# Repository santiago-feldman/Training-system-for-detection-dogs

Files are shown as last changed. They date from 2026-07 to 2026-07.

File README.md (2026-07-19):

# Training-system-for-detection-dogs
Electronic engineering final project (electronic equipment design) | ITBA

### Group members:

- Feldman, Santiago
- Greco, Trinidad Eugenia
- Rodriguez, Juan Martín
- Singermann, Nicolás Pablo

### Faculty staff:

- Carrillo del Pino, Manuel Esteban
- Gasparini, Ignacio
- Orchessi, Walter Hugo
- Regazzoni, Pablo

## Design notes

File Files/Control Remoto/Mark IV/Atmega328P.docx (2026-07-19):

Conexiones básicas para el Atmega 328P (DIP)

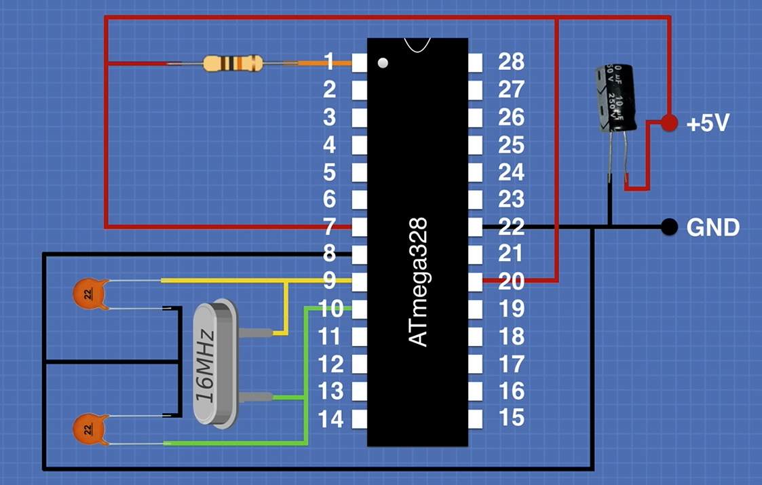
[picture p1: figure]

R de 10k, multicapas de 22pF, y electrolítico de 10 micros (opcional)

- Notar que este conexionado no contempla el regulador de 5v, asume que le llega la tensión ya regulada.
- Tampoco tiene un botón de Reset

Como es de encapsulado DIP, se puede cargar el código de 2 formas distintas:

- Simplemente colocarlo en la placa del arduino uno y cargar el programa
- Teniendo el micro en la proto, usar Tx, Rx y Reset del arduino uno para cargar el programa

En caso de ser SMD, se puede usar un adaptador FTDI (Básicamente son USB to Serial Converters)

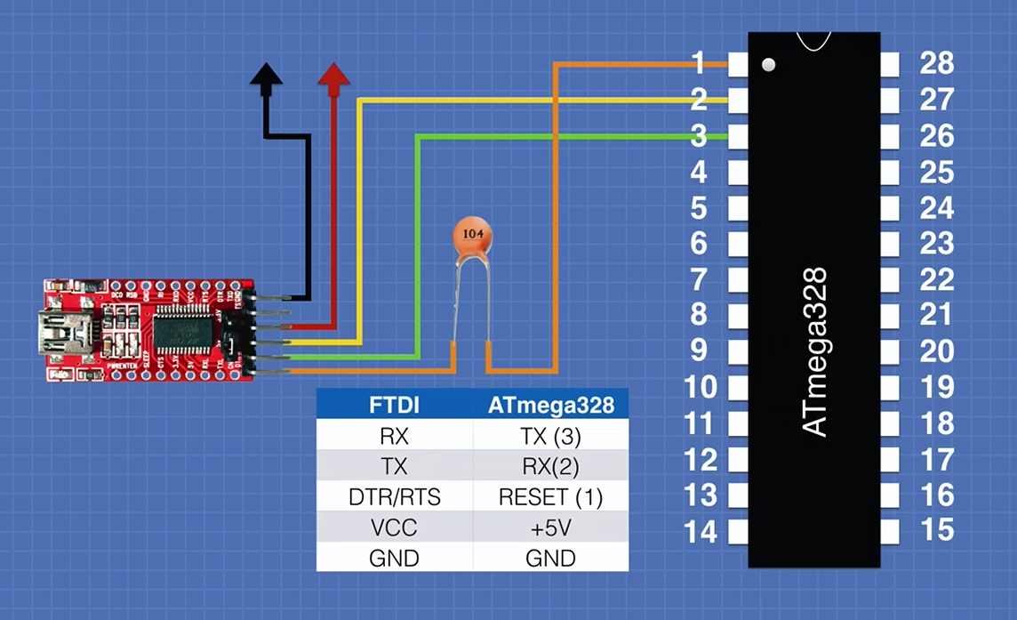
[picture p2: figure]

Multicapa de 100n. Fuente: https://www.youtube.com/watch?v=Sww1mek5rHU&t=915s

(https://www.youtube.com/watch?v=Sww1mek5rHU&t=915s)

Importante al hacer PCB con el 328P SMD:

- Colocar un botón de RST en el PCB
- Dejar salida de 2 pines, conectados a Tx y Rx, para poder cargar programa al micro en caso de ser necesario (asegurarse que antes de desoldarlo tenga cargado el programa indicado y que esté funcionando)
- 2 entradas para la alimentación de la pila, idealmente un molex o soldar directo
- 2 salidas para el pulsador del control

Video Clave para cargarle un programa al 328P

- https://www.youtube.com/watch?v=jy-UyMF7zr8

En resumen, se usa otro arduino (use el Nano) para cargarle un programa a otro micro (328P) vía SPI. Para esto primero se le carga un programa de ejemplo al Nano llamado ArduinoISP. Seleccionando en Herramientas → Programador → Arduino as ISP, le cargué el bootloader al 328P, y luego el Sketch → Cargar usando programador, va a subir el programa que se tenga abierto al 328P!!

En el PCB esto va a tener leves cambios, no voy a usar el adaptador FTDI, por lo que necesita 4 pines que salgan hacia afuera para poder programarlo (MISO, MOSI, SCK, SS). Y no olvidarse que el NRF24l01 usa SPI también

Próximos pasos (cada paso asume que el anterior fue exitoso)

1. Probar en Proto alimentando al 328P con el regulador de 3.3V (En teoría se puede alimentar al micro con 3.3V)
2. Probar el control remoto con el 328P como control, y el arduino Nano como el lanzador. Acá estar atento a si el regulador suministra la suficiente corriente para el 328P + NRF24l01
3. Ya se está listo para diseñar el PCB, desoldar el 328P SMD del Nano, para ver su encapsulado
4. Diseñar PCB con las consideraciones debidas (atento al encapsulado del 328P SMD). Que el PCB tenga botón de reset (puede ser SMD) y un LED (también SMD) simplemente para tener la posibilidad de debugeo
5. Hacer PCB
6. Testear control remoto
7. Diseñar carcaza para el control remoto

Imágenes útiles

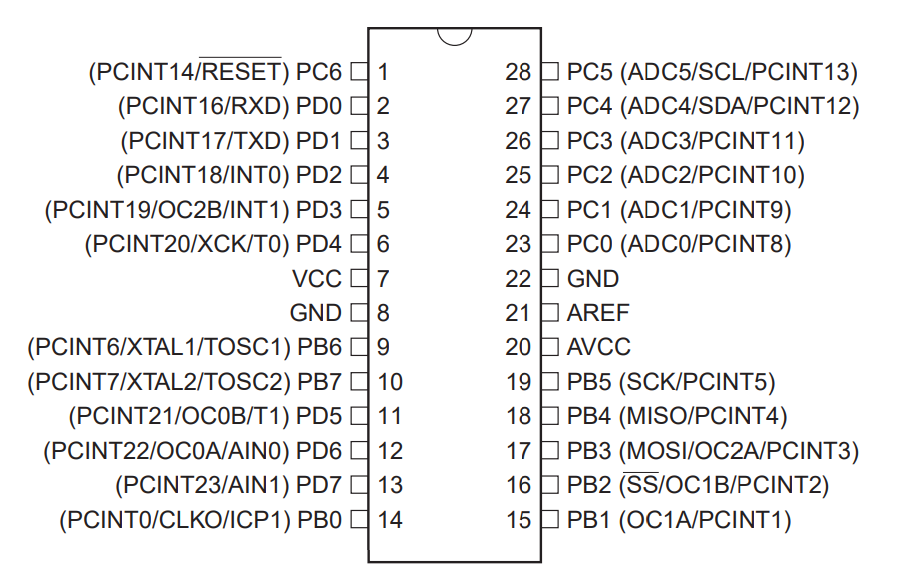
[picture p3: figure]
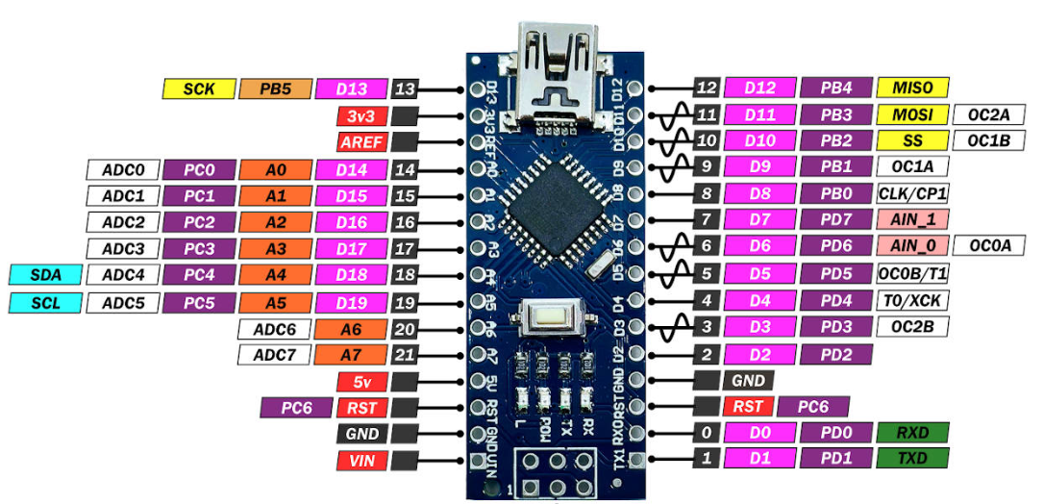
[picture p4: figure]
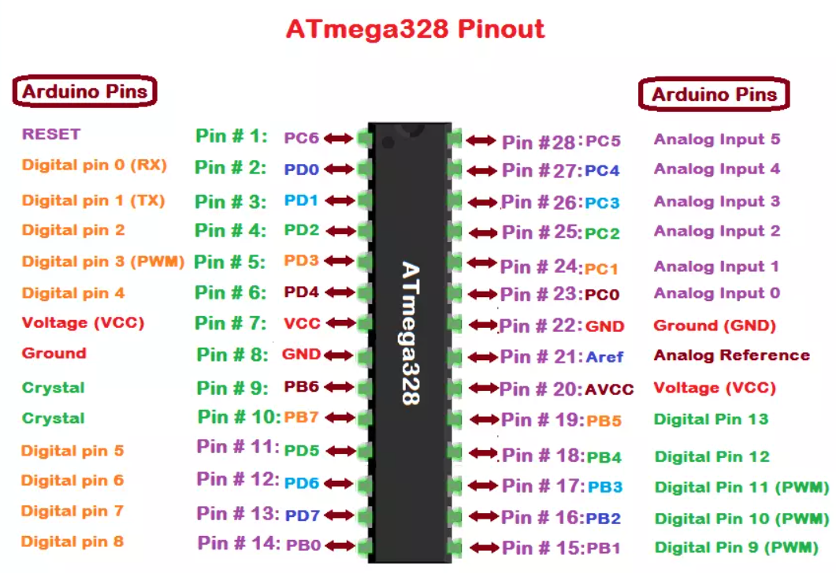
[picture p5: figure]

- Comenzando con el PCB

El arduino nano tiene un ATMEGA328P SMD de 32 pines, bastante seguro que es el encapsulado MLF, el cual tiene un pad en la cara inferior, que debe ser soldado a GND.

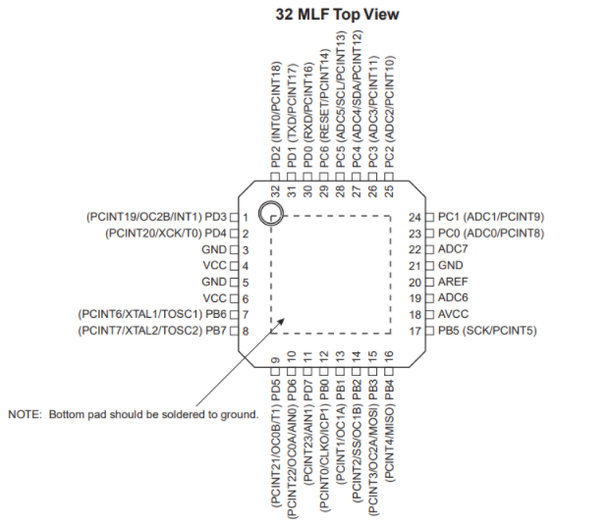
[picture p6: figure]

Me parece una buena idea poner un LED SMD para posible debugeo → SMD 1206

No olvidarse de colocar 2 entradas para la alimentación con la pila (pueden ser 2 pads), y 2 salidas para el pulsador

Tambien se puede agregar un SW SMD para el reset

Para el regulador SMD → SOT-223, y la tab es Vout

Atento a los footprints antes de planchar → Especialmente al SW del Reset, al LED, al Electrolítico SMD, y al micro

Hay que cambiar el código! Conecte el Led de Debug a PD2!

Y se conecto el 2do botón!

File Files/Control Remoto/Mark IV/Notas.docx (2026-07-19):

Cosas a mejorar frente al Mark III

PCB

- Que el PCB tenga agujeros para sujeción a la carcasa (Pueden ser 2/3/4)
- Chequear la orientación del NRF24
- Ambos botones conectados a pines con IRQ
- Tener pin de salida al RST del micro para poder cargar programa más fácilmente
- Necesito preset para ajustar las resistencias para la boost
- Las salidas a los pulsadores y a la alimentación con molex, no soldado a la placa
- Que el cristal sea SMD (Usar el que ya se tiene del Nano)

Carcasa

- Considerar en la carcasa que adentro va el portapila AAA
- Ver de usar botones más pequeños
- Que la carcasa tenga el logo

Cambios en el código

- Los pulsadores ahora están en PD2 y PD3 que tienen IRQ externas
- El LED para debugeo ahora está en PD4

Testeos antes de hacer la placa

- Chequear todos los footprints antes de planchar, especialmente el del cristal SMD

Testeos después de hacer la placa

- Probar tensión de salida de la boost previo a conectar el NRF24
- Sacar buenas fotos a la placa antes de hacer nada

Lista para comprar componentes

- MCP1640 (SOT-23) x1 (https://www.elemon.com.ar/products/detail/code/CI2707272)
- C 4.7uF multicapa SMD (0805) x1
- C 4.7uF multicapa SMD (1206) x1
- C 10uF multicapa SMD (0805) x1
- C 10uF multicapa SMD (1206) x1
- L 4.7uH SMD (1007) x1 (https://www.elemon.com.ar/products/detail/code/FI1512580)
- R 750K SMD (0805) x1
- R 220K SMD (0805) x1
- R 560K SMD (0805) x1
- R 2K SMD (0805) x1
- Preset 10k

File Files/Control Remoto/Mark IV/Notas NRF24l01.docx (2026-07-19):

- NRF24l01

Es un transceptor (Emisor y Receptor) de radiofrecuencia a 2.4GHz que usa modulación FSK, logrando alta inmunidad al ruido.

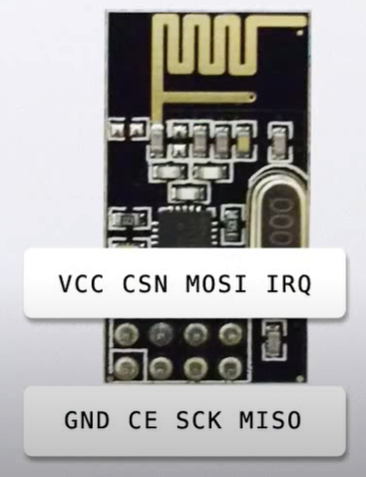
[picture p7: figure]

Pinout NRF24l01

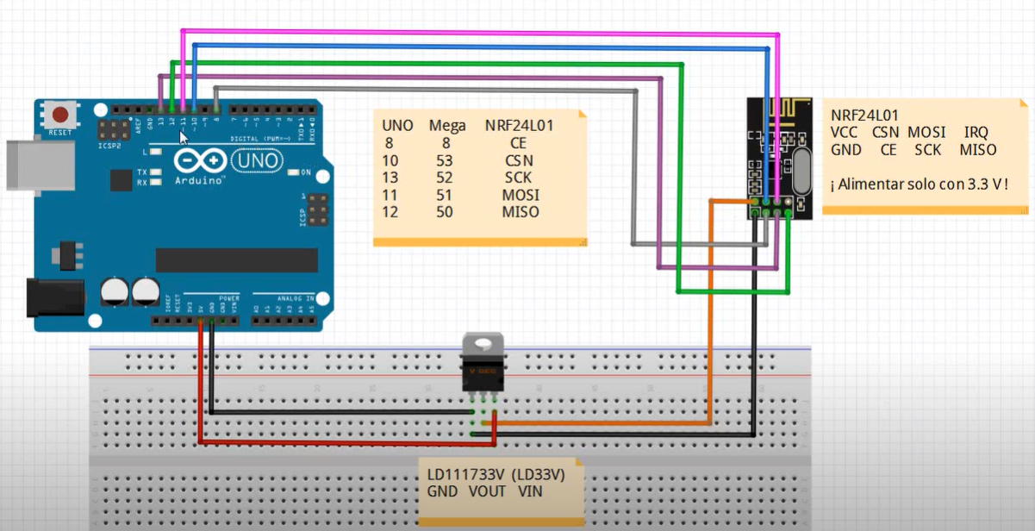
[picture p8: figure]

Dispositivo Base

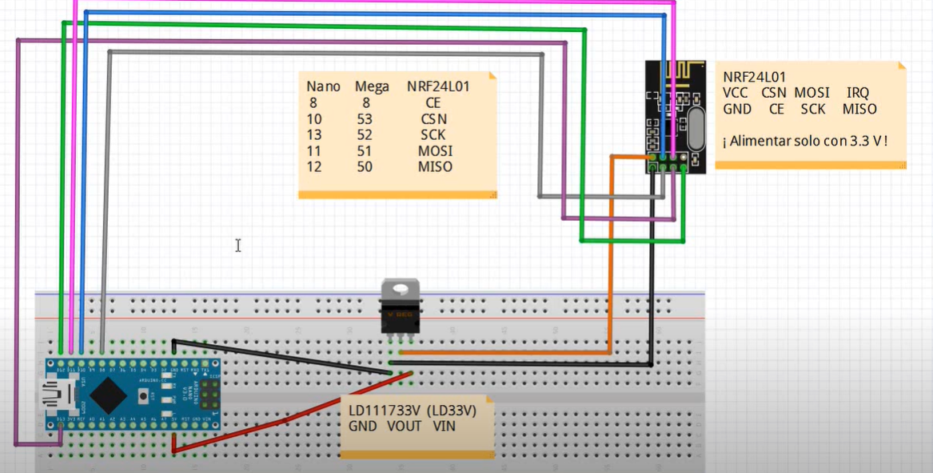
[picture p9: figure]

Dispositivo Remoto

Se verifica la integridad de los datos recibidos (con un CRC)

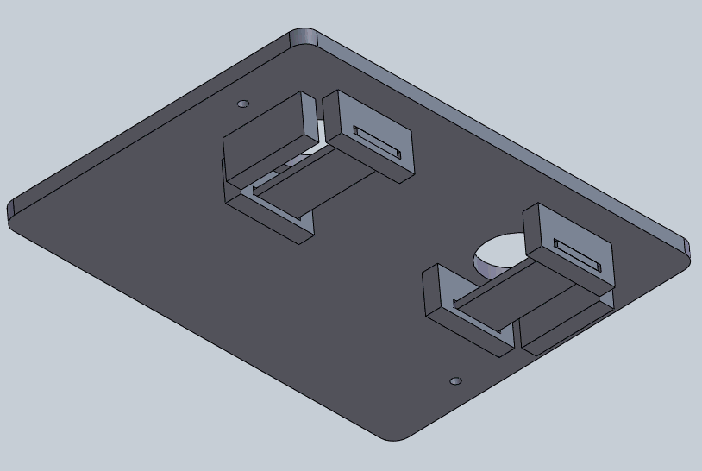
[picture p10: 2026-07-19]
Files/Control Remoto/Sujecion_RC.png

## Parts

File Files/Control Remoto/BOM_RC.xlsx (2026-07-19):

Designator | Descripción | Quantity
C1, C2 | 22pF | 2
C3 | 4.7uF | 1
C4 | 10uF | 1
D1 | AP1608SGC (Red Led) | 1 | Red LED SMD
J1, J2, J3 | MOLEX2 | 3
J4 | JUMPER | 1
L1 | CB2518T4R7MR (4.7uH) | 1 | 4.7uH SMD
P1 | NRF24 | 1
R1, R2 | 10k | 2
R3, R4 | 1k | 2
R5 | 560k | 1
R6 | 2k | 1
R8 | 750k | 1
R9 | 220k | 1
R10 | 10k | 1
S1 | SW | 1
SUJECION 1, SUJECION 2 | SUJECION | 2
U1 | ATMEGA328PB-ANR | 1
U2 | MCP1640CT-I/CHY | 1
Y1 | CSTNE16M0V530000R0 (Cristal 16MHz) | 1 | Cristal 16MHz SMD

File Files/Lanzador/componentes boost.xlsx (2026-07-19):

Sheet: Hoja1
2° Etapa | UC3843 | Comentario |  | 1° Etapa | MT3608 | Comentario
I_sense | 0.5 | Configurada |  | Io_max | 0.25
Vin | 12 | Salida de la primer etapa |  | Vin | 3.7
Vo_max | 90 |  |  | Vo | 12
Vo_min | 40 |  |  | I_in_media | 0.811 | Suponiendo CCM y eficiencia 100%
fs | 100000 | hasta 500kHz |  | I_in_potencia | 0.9538950715 | Por balance de Potencias y eficiencia n
L_boundary | 0.000208 | Buscamos menor para DCM |  | n | 0.85 | Eficiencia del módulo
Componentes | Valor | Comentario | Modelo | link
L | 0.0001 | I_max = 0.5A según I_sense
C_t | 2.2e-09 | Según grafica datasheet, ceramico preciso |  |  |  | MOSFET | IRF630 | Vds>200V, I_ds>1A, P
R_t | 7818.181818 | R_t para 100kHz |  |  |  | Diodo Ultra Rápido | UF4005 | through hole
R_t_real | 8200 |  |  |  |  | Diodo Ultra Rápido | ES1J | SMD
fs | 95343.68 | fs para Rt real
L_boundary_real | 0.0002181581395 | L boundary para fs real
t_dead | 3e-07 | según grafica Ct=1nF->t_dead= 300ns
D_max | 0.97 | Duty máximo según Ct, mínimo 0.87
R_sense | 2 | Vth = 1V, define maxima corriente en L.
R_lp | 1000 | RC para señal de sense
C_lp | 4.7e-10 | RC para señal de sense
Rf_top_max | 50000 | i_bias=2uA, DeltaVo_max=100mV
DeltaVo | 0.44 | Consecuencia de i_bias=2uA
Rf_top | 220000
Rf_bottom | 82000.00
Vo | 9.21 | Vo según Rtop y Rbott
Rf_bottom_min | 6285.71 | Vo_max
Rf_bottom_max | 14666.67 | Vo_min
Rf_bott_1 | 6200
Rf_bott_2_1 | 50000 | preset
Rf_bott_2_2 | 10000
Rf_bott_real | 14533.33
i_f | 0.000298013245 | Corriente de perdida en feedback
Rcomp | 100000 | Mínimo por OpAmp interno, Rcomp>7k
Ccomp | 1e-08
f_polo | 159.15
G_dc | 1.67
diodo_pwm | SS14 | Shottky, Vf<0.3V a 200mA
Rgate | 22 | Limita la corriente de gate
Igate_max | 0.545
C_vcc | 1e-07 | Ceramico multicapa
C_vref | 1e-06 | Ceramico multicapa

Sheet: Hoja2
0.002
0.5ms | 1ms | 1000
 |  | 2000

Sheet: Comp
2° Etapa | UC3843 | Comentario |  | 1° Etapa | MT3608 | Comentario
I_sense | 0.5 | Configurada |  | Io_max | 0.25 |  |  | Eo | 13.536 |  | Epump | 0.000846
Vin | 12 | Salida de la primer etapa |  | Vin | 3.7 |  |  | Co | 0.00188 |  | Cpump | 4.7e-07
Vo_max | 90 |  |  | Vo | 12 |  |  | Vo | 120 |  | Vpump | 60
Vo_min | 40 |  |  | I_in_media | 0.811 | Suponiendo CCM y eficiencia 100% |  |  |  |  | Npump | 16000
fs | 100000 | hasta 500kHz |  | I_in_potencia | 0.9538950715 | Por balance de Potencias y eficiencia n |  |  |  |  | Ts | 1e-05
L_boundary | 0.000208 | Buscamos menor para DCM |  | n | 0.85 | Eficiencia del módulo |  |  |  |  | T_total | 0.16
Componentes | Valor | Comentario | Modelo | link
L | 0.0001 | I_max = 0.5A según I_sense
C_t | 2.2e-09 | Según grafica datasheet, ceramico preciso |  |  |  |  |  | Vds>200V, I_ds>1A, P
R_t | 7818.181818 | R_t para 100kHz
R_t_real | 8200
fs | 95343.68 | fs para Rt real |  |  |  | Diodo Ultra Rápido | UF4005 | through hole
L_boundary_real | 0.0002181581395 | L boundary para fs real
t_dead | 3e-07 | según grafica Ct=1nF->t_dead= 300ns
D_max | 0.97 | Duty máximo según Ct, mínimo 0.87
R_sense | 2 | Vth = 1V, define maxima corriente en L. 1/4W |  |  |  |  |  |  | Cantidad |  | Componente | Modelo | Tipo | Cantidad
R_lp | 1000 | RC para señal de sense |  |  | x | L | 100uH, 1A | SMD | 2 | elemon | Diodo Ultra Rápido | ES1J | SMD | 2
C_lp | 4.7e-10 | RC para señal de sense |  |  | x | C_t | 2.2nF,16V,NP0 | 1206 | 5 | elemon | MOSFET | IRF630 | THT | 2
Rf_top_max | 50000 | i_bias=2uA, DeltaVo_max=100mV |  |  |  | R_t | 8.2k | 1206 | 5 |  | diodo Schottky | SS14 | SMD | 2
DeltaVo | 0.44 | Consecuencia de i_bias=2uA |  |  | x | R_sense | 2 ,1/4W o mas | 1206 | 5 | elemon | Driver PWM | UC3843D8 | SMD | 2
Rf_top | 220000 |  |  |  |  | R_lp | 1k | 1206 | 5 |  | Regulador 5V | UA78M05 | SMD | 2
Rf_bottom | 6800.00 |  |  |  |  | C_lp | 470p,16V,NP0 | 0805 | 5 | elemon | Oscilador | NE555DR | SMD | 2
Vo | 83.38 | Vo según Rtop y Rbott |  |  |  | Rf_top | 220k | 1206 | 5 |  | MOSFET | IRF640S | SMD | 2
Rf_bottom_min | 6285.71 | Vo_max |  |  |  | Rf_bott_1 | 6.2k | 1206 | 5
Rf_bottom_max | 14666.67 | Vo_min |  |  |  | Rf_bott_2 | 10k | 1206 | 5
Rf_bott_1 | 6800 |  |  |  |  | Rf_preset | 50k | 1206 | 5 | elemon
Rf_bott_2_1 | 0 | preset |  |  |  | R_comp | 100k | 0805 | 5
Rf_bott_2_2 | 10000 |  |  |  | x | C_comp | 10n,16V,NP0 | 0805 | 5 | elemon
Rf_bott_real | 6800.00 |  |  |  | x | R_g | 22, 1/4W | 1210 | 5 | elemon
i_f | 0.0003968253968 | Corriente de perdida en feedback |  |  |  | C_vcc | 100n,16V | 1206 | 5
Rcomp | 100000 | Mínimo por OpAmp interno, Rcomp>7k |  |  |  | C_vref | 1u,16V | 1206 | 5
Ccomp | 1e-08 |  |  |  |  | C_vin_1 | 100n,16V | 1206 | 2
f_polo | 159.15 |  |  |  | x | C_vin_2 | 470u,25V | THT/SMD | 2 | elemon | CA3629295
G_dc | 15.16 |  |  |  |  | Co_1 | 100n, 150/200V | THT/SMD | 2
diodo_pwm | SS14 | Shottky, Vf<0.3V a 200mA |  |  |  | Co_2 | 100u, 150/200V | THT/SMD | 2
Rgate | 22 | Limita la corriente de gate |  |  | x | Diodo Ultra Rápido | ES1J | SMD | 2 | elemon
Igate_max | 0.545 |  |  |  | x | MOSFET | IRF630 | THT | 2 | elemon
C_vcc | 1e-07 | Ceramico multicapa |  |  | x | diodo Schottky | SS14 | SMD | 2 | elemon
C_vref | 1e-06 | Ceramico multicapa |  |  | x | Driver PWM | UC3843D8 | SMD | 2 | gm elect
 |  |  |  |  |  | Regulador 5V | UA78M05 | SMD | 2 | elemon
 |  |  |  |  |  | Oscilador | NE555DR | SMD | 2 | elemon
f_lp | 338799.2953
f_lp_2
clp2 | 1e-09
rlp2 | 470

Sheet: Transistores Rdson
Item | Modelo | Cantidad
1 | AO3401 | 5
2 | AO3400 | 5 | 0.0175
3 | AO4423 | 6
4 | AO4407 | 4
5 |  | 3

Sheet: SoftStartSW
SW1 |  |  |  |  | SW2
Calculos |  |  | Componentes |  | Calculos |  |  | Componentes
I_inrush | 1.00 |  | I_inrush | 1.055916893 | I_inrush | 0.25 |  | I_inrush | 0.09488518519 | 0.09488518519
R1 | 100000 | R pull up | R1 | 100000 | R1 | 100000 | R pull up | R1 | 100000
R2 | 2777.78 | R g | R2 | 2700 | R2 | 4347.83 | R g | R2 | 2700
C1 | 8.586666667e-09 |  | C1 | 8.2e-09 | C1 | 2.51447619e-08 |  | C1 | 1e-07
i_g_r1 | 1.352380952e-05 |  | i_g_r1 | 1.4e-05 | i_g_r1 | 9.688095238e-05 |  | i_g_r1 | 9.7e-05
i_g_r2 | 0.0008451428571 |  | i_g_r2 | 0.0008518518519 | i_g_r2 | 0.0005317380952 |  | i_g_r2 | 0.0008518518519
i_g | 0.0008586666667 |  | i_g | 0.0008658518519 | i_g | 0.0006286190476 |  | i_g | 0.0009488518519
gfm | 21 |  |  |  | gfm | 21
VDD | 3.7 |  | VDD | 3.7 | VDD | 12 |  | VDD | 12
Vth | 2.3 |  |  |  | Vth | 2.3
Vpl | 2.348 |  | Vpl | 2.300 | Vpl | 2.312 |  | Vpl | 2.300
Vsg | 3.6 |  | Vg | 0.09727361246 | Vsg | 11.5 |  | Vg | 0.3154819864
Vsg_max | 25 |  | Vsg | 3.602726388 | Vsg_max | 25 |  | Vsg | 11.68451801
Ciss | 2.6e-09 |  |  |  | Ciss | 2.6e-09
Coss | 3.7e-10 |  |  |  | Coss | 3.7e-10
Cload | 1e-05 |  | Cload | 1e-05 | Cload | 1e-05 |  | Cload | 1e-05
 |  |  | dt | 3.50406365e-05 |  |  |  | dt | 0.001264686366
 |  |  | V12 | 10
 |  |  | Rtop | 100000
 |  |  | Rbott | 82000
 |  |  |  | 4.505494505

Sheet: Componentes DriverLanzador
Switch Load |  |  |  | Disparo Rele |  |  |  | Bleeding |  |  |  | PlacaESP
Componente | Modelo | Cantidad | Proveedor | Componente | Modelo | Cantidad | Proveedor | Componente | Modelo | Cantidad | Proveedor | Componente | Modelo | Cantidad | Proveedor
MOSFET-P | IRF7425PBF | 2 | Elemon | optocoplador | LTV817S | 1 | Elemon | zener 8.2V | BZV55C8V2 | 1 | SDV | Sensor | BME280 | 1 | Elemon
MOSFET-N | 2N7002 | 2 | SDV | diodo rele | 1n4148W | 1 | SDV | zener 12V | BZV55C12 | 1 | SDV | Regulador LDO | MCP1826S | 2 | Elemon
Cap_GD | 10n | 2 | SDV | diodo solenoide | ES1J | 1 | Elemon | MOSFET-N | IRFL110 | 1 | Elemon | Pila | P18650C | 1 | SDV
 |  |  |  | Rele | HJQ-13F-2ZP | 1 | SDV | MOSFET-N | 2N7002 | 1 | SDV
 |  |  |  | Rdiodo | 190 |  |  | Res | 2.7k 3W | 4 | SDV
Boost 80V
Componente | Modelo | Cantidad | Proveedor
Co | 47uF 160V | 1 | SDV

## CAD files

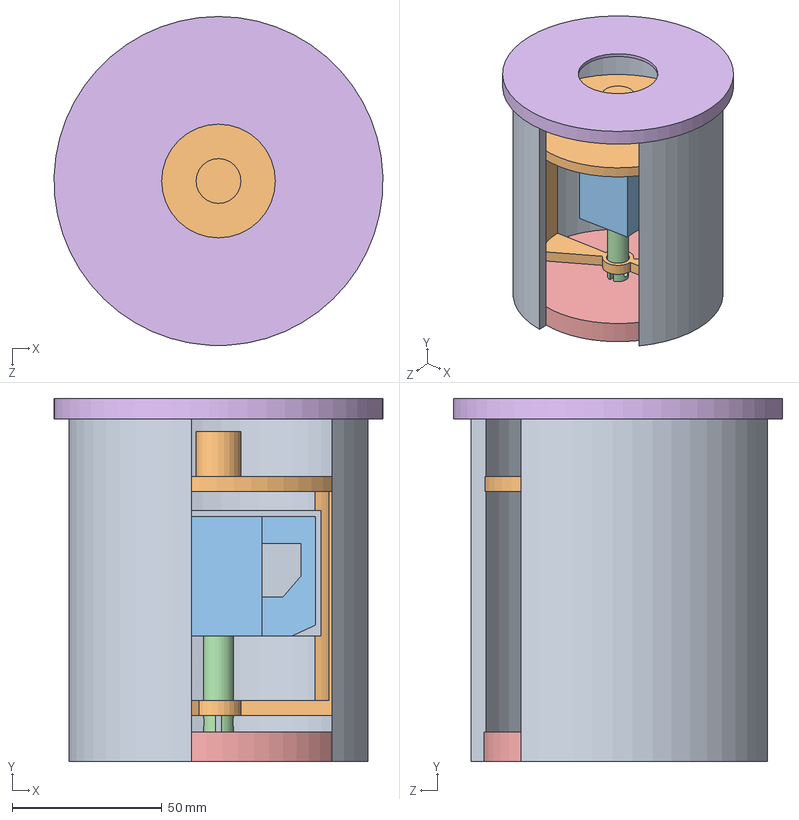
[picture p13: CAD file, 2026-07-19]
Files/SolidWorks/Lanzador/Ensamblaje lanzador.SLDASM
110.0 x 121.5 x 110.0 mm
Lanzador cilindrico
Lanzador cilindrico p2
modelo solenoide
palito
tapa lanzador
tapa pelota

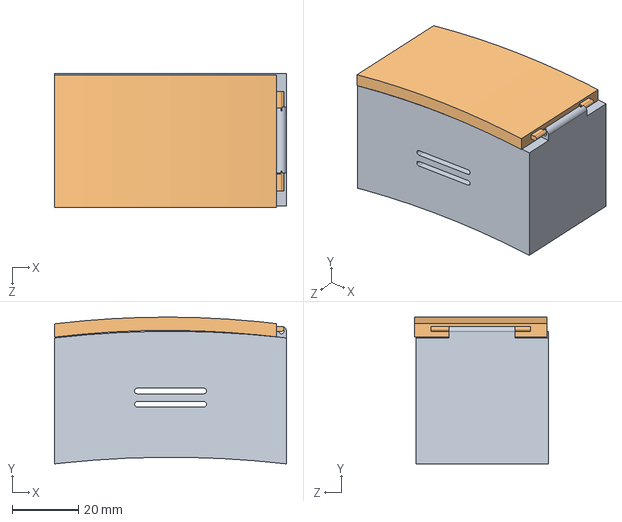
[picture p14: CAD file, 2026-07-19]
Files/SolidWorks/Lanzador/Ensamblaje1.SLDASM
70.0 x 44.3 x 40.3 mm
TAG_p1
Tapa_p1

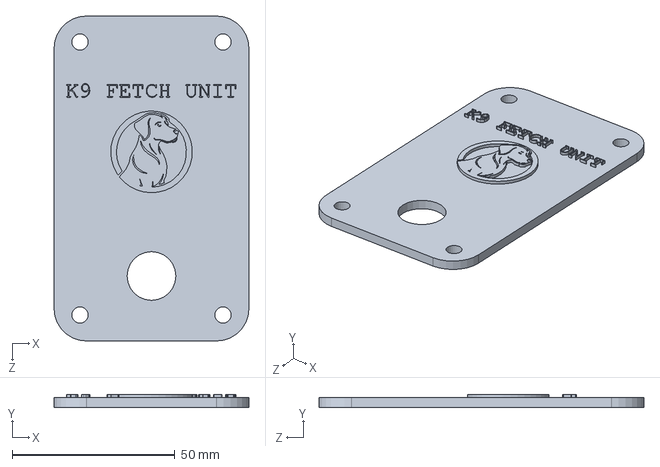
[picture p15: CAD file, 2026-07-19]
Files/Control Remoto/Mark IV/Solid/Tapa_RC.SLDPRT
60.0 x 4.00 x 100.0 mm

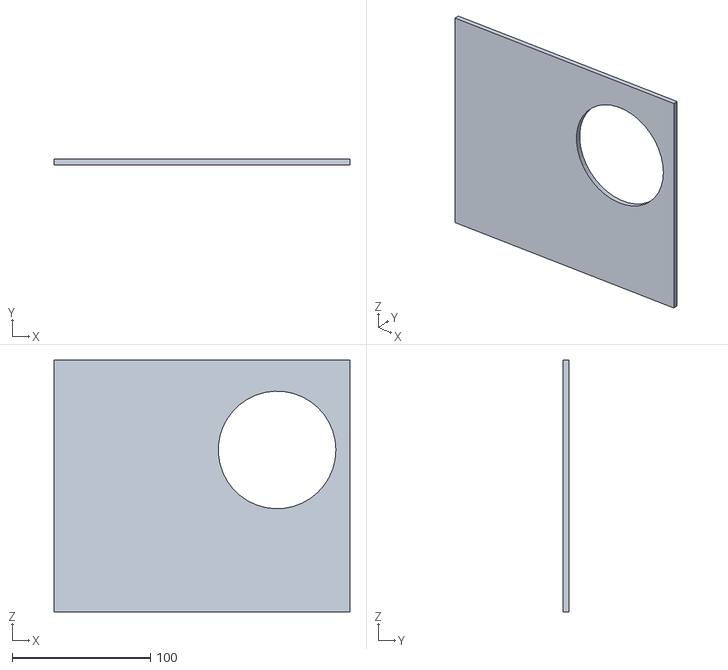
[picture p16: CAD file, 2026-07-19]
Files/SolidWorks/Lanzador/tapa_lanzador_pelota.stl
214.0 x 4.00 x 182.0

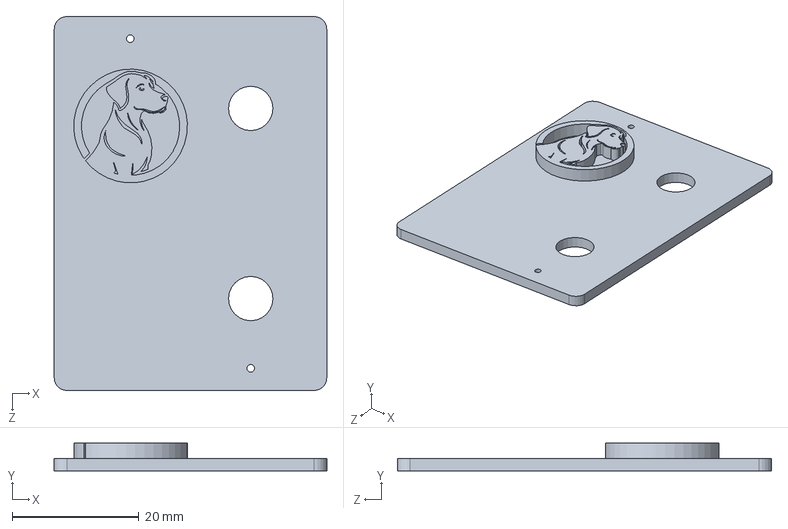
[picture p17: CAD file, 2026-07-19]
Files/SolidWorks/Logo/RC_MK4_Tapa.SLDPRT
43.0 x 4.40 x 59.0 mm

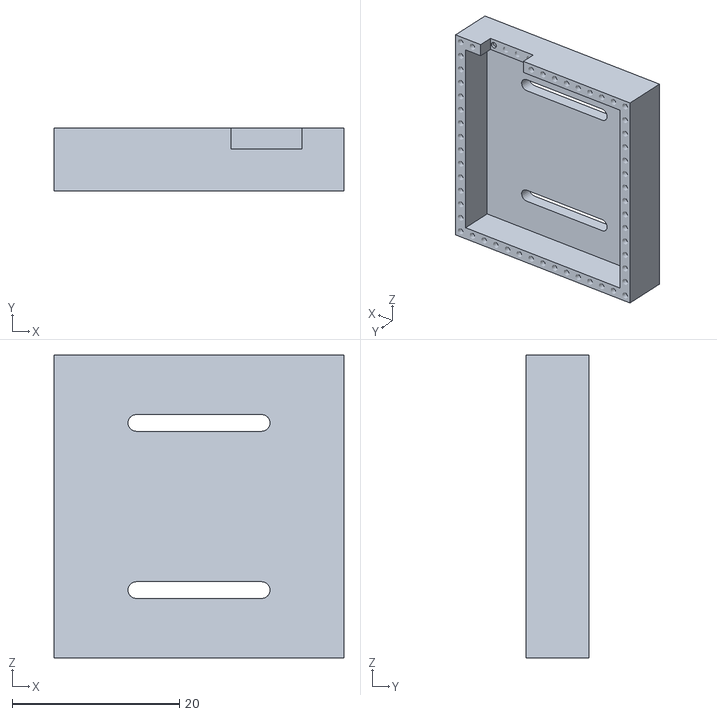
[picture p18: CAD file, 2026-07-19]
Files/SolidWorks/TAG/Tapa 1.STL
34.7 x 7.50 x 36.2

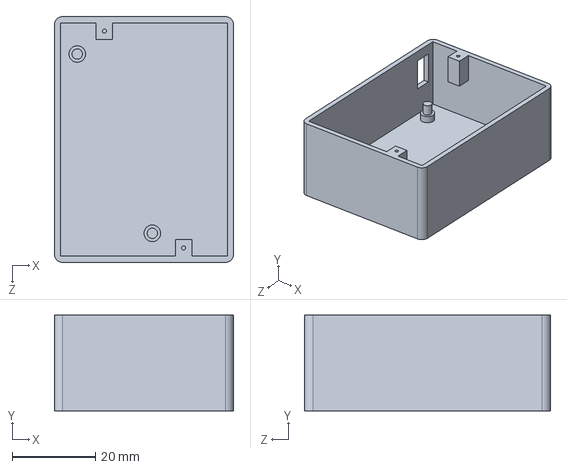
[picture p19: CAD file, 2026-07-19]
Files/Control Remoto/Mark IV/Solid/RC_MK4_Base.SLDPRT
43.0 x 23.0 x 59.0 mm

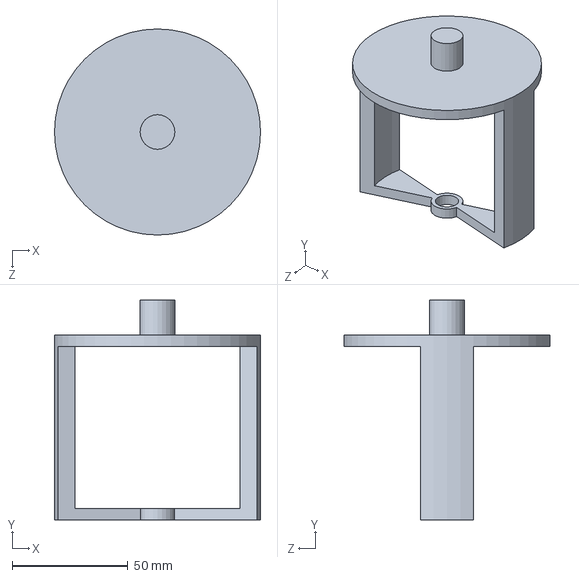
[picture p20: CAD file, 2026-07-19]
Files/SolidWorks/Lanzador/Lanzador cilindrico p2.SLDPRT
89.0 x 95.0 x 89.0 mm

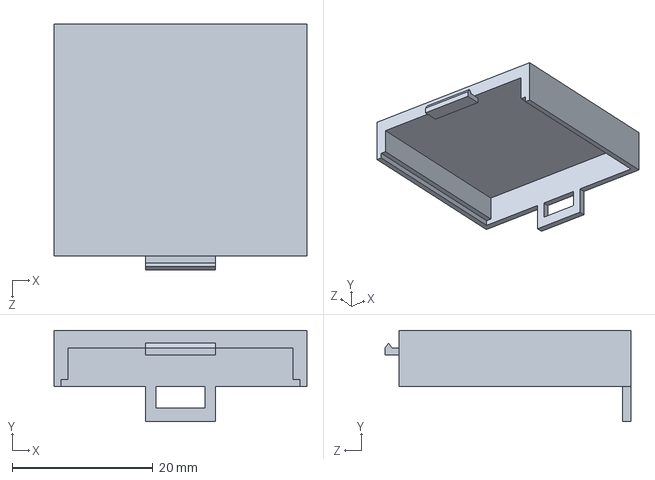
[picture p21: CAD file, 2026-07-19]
Files/SolidWorks/TAG/tapa2_encastre.SLDPRT
36.0 x 13.0 x 35.0 mm

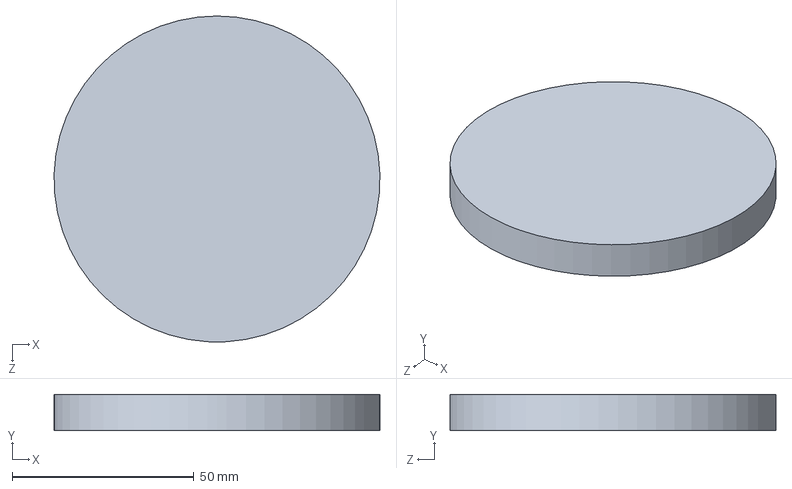
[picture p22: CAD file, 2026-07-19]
Files/SolidWorks/Lanzador/tapa lanzador.SLDPRT
89.8 x 10.0 x 89.8 mm

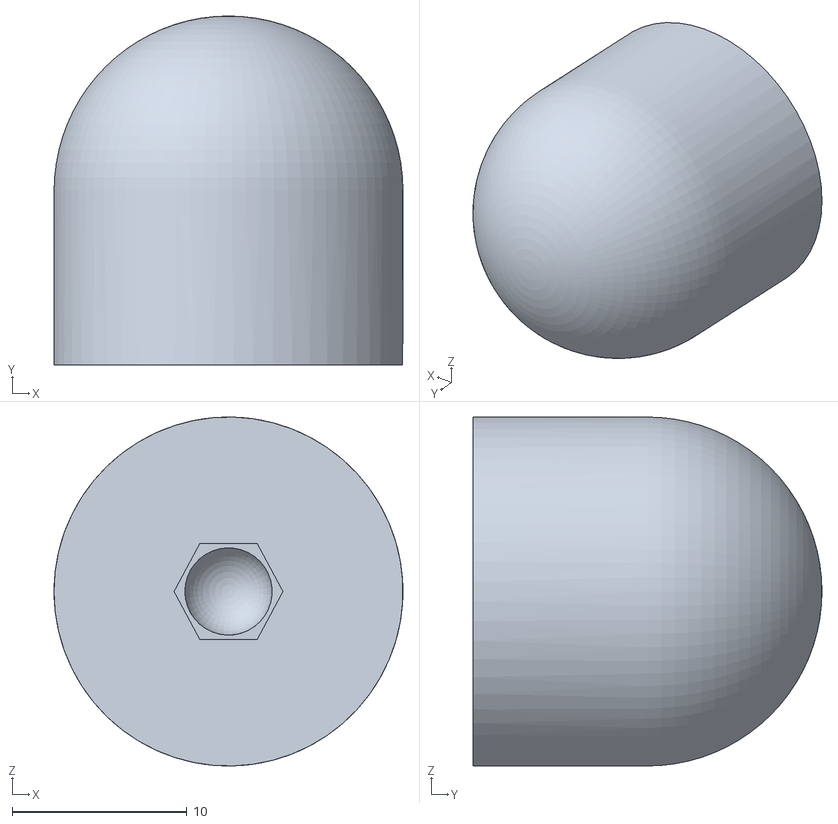
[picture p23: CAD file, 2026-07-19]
Files/SolidWorks/TAG/lanzador 2.STL
20.0 x 20.0 x 20.0

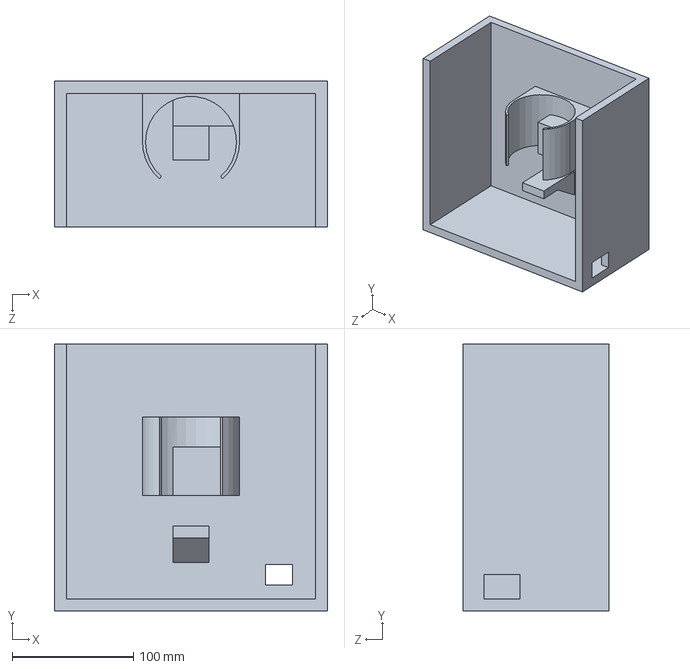
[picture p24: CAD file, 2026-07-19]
Files/SolidWorks/Lanzador/pieza1_lanzador.SLDPRT
225.0 x 220.0 x 120.0 mm

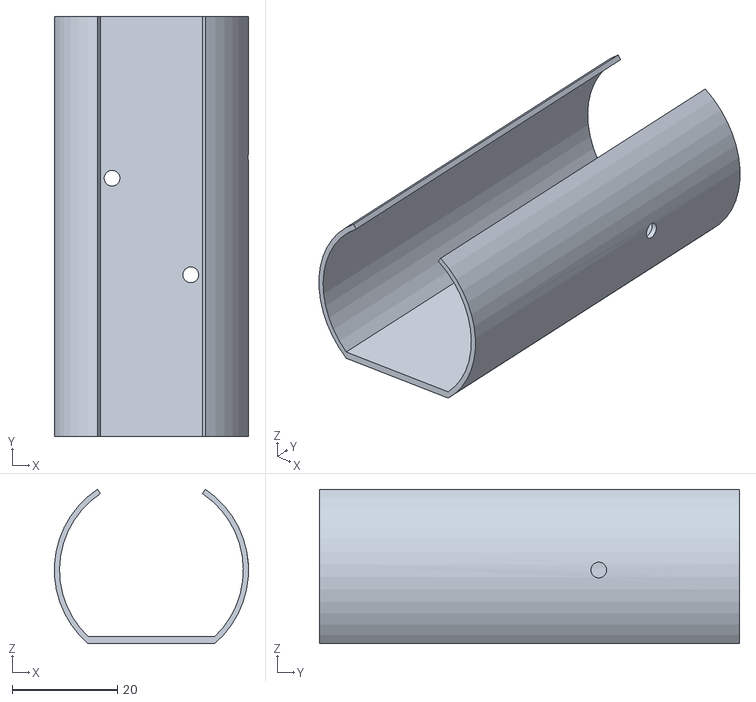
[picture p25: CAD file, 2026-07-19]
Files/SolidWorks/TAG/lanzador 1.STL
37.0 x 80.0 x 29.4

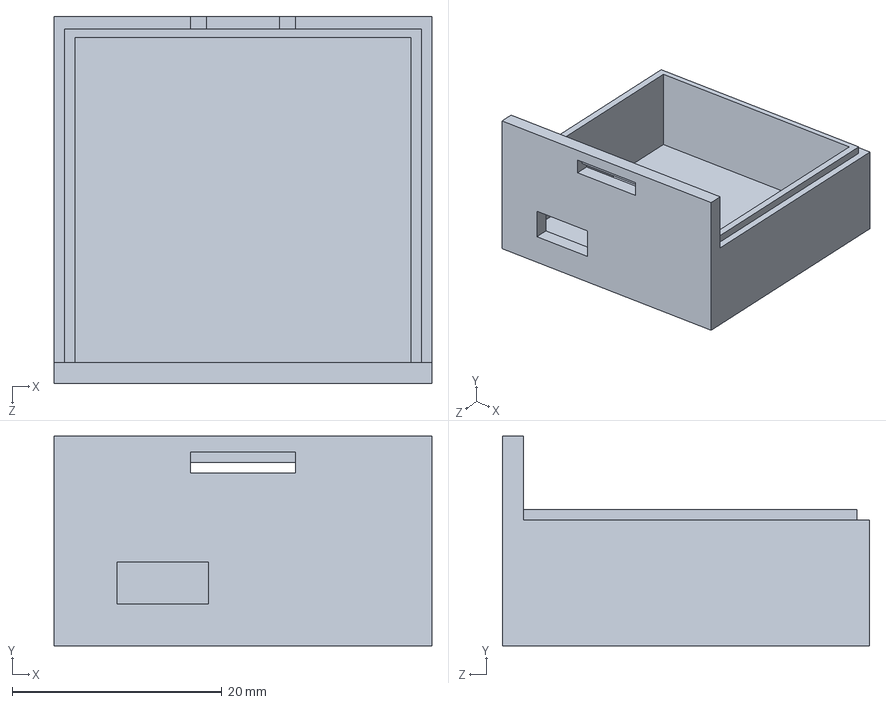
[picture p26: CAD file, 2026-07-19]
Files/SolidWorks/TAG/tapa1_encastre.SLDPRT
36.0 x 20.0 x 35.0 mm

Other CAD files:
Files/SolidWorks/TAG/Tapa 2.STL
Files/SolidWorks/Lanzador/modelo solenoide.SLDPRT
Files/SolidWorks/Lanzador/Ensamblaje lanzador.iam
Files/SolidWorks/Lanzador/Lanzador cilindrico p2.STL
Files/SolidWorks/Lanzador/Lanzador cilindrico.SLDPRT
Files/SolidWorks/Lanzador/Lanzador cilindrico.STL
Files/SolidWorks/Lanzador/PCB_SS_SL_modelo3D.iam
Files/SolidWorks/Lanzador/Pared_lateral_estructura.ipt
Files/SolidWorks/Lanzador/Pared_lateral_estructura.stl
Files/SolidWorks/Lanzador/esquematico_microcontrolador_modelo3D.iam
Files/SolidWorks/Lanzador/estructura_lanzador.stl
Files/SolidWorks/Lanzador/estructura_pieza1.ipt
Files/SolidWorks/Lanzador/estructura_pieza1.stl
Files/SolidWorks/Lanzador/modelo pila.ipt
Files/SolidWorks/Lanzador/modelo placa.ipt
Files/SolidWorks/Lanzador/modelo solenoide.stl
Files/SolidWorks/Lanzador/palito.SLDPRT
Files/SolidWorks/Lanzador/pieza1_lanzador.STL
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

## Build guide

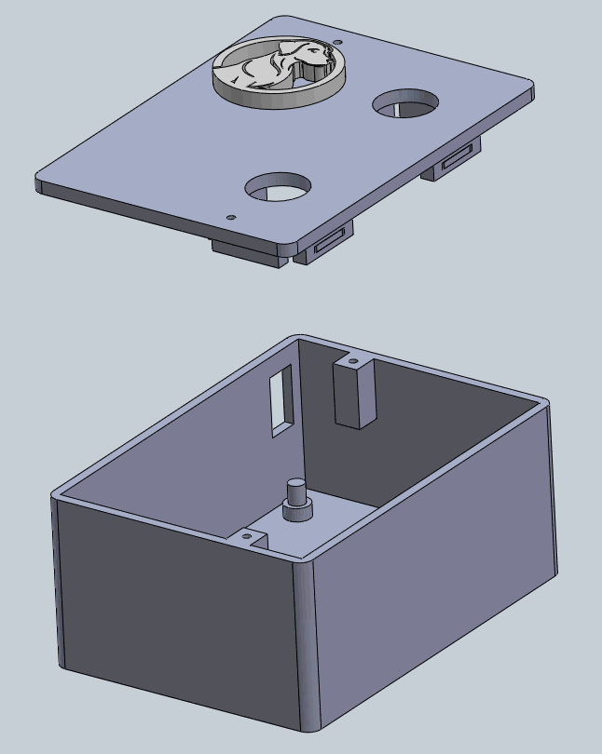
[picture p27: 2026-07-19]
Files/Control Remoto/Ensamble_RC.png

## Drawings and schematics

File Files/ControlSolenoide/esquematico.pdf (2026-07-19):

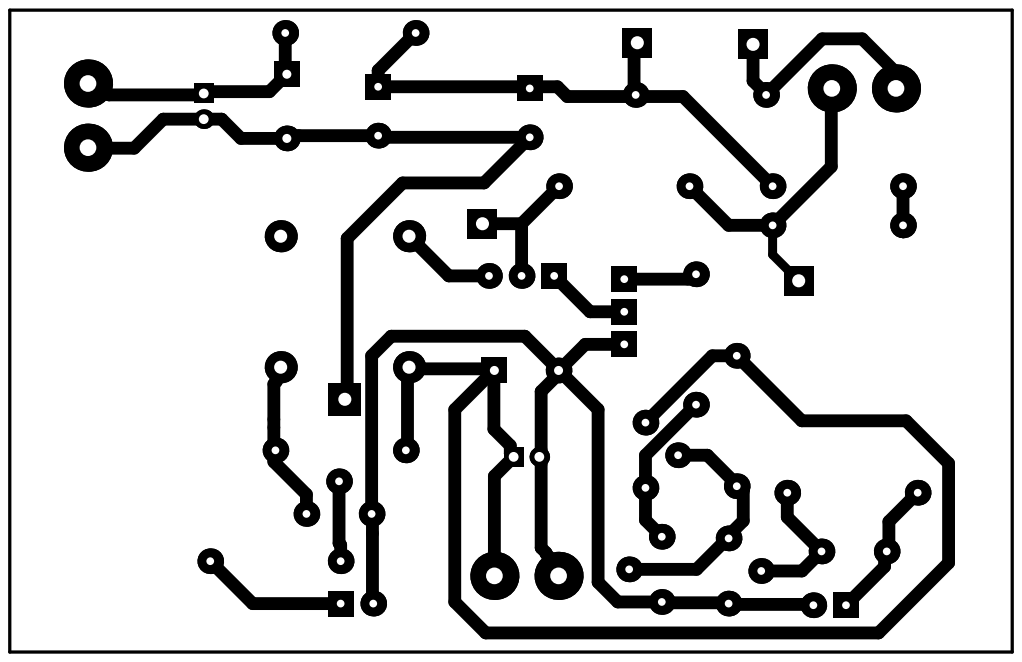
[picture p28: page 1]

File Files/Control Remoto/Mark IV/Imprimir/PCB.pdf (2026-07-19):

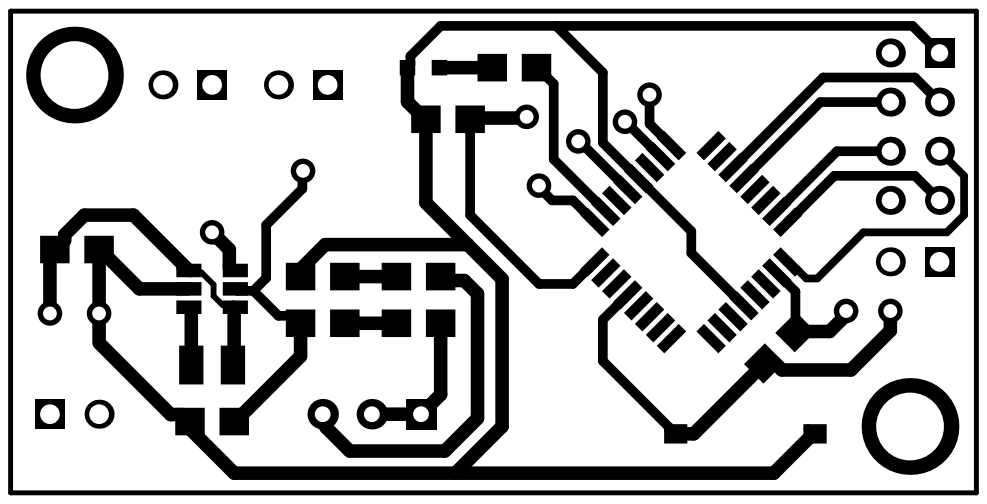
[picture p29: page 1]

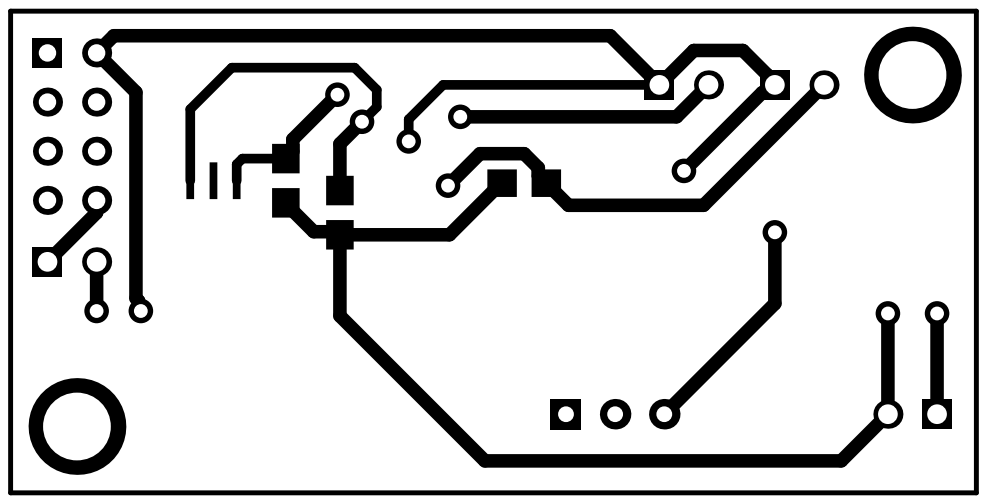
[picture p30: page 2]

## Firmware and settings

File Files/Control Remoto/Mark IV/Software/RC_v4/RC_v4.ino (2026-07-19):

//********************************************************
//            Control Remoto con NRF24 (Cliente)
//********************************************************

#include <SPI.h>
#include <RH_NRF24.h>
#include <LowPower.h>

//Conexiones
#define BTN_PIN_1 2
#define BTN_PIN_2 3
#define CE_PIN 7
#define CSN_PIN 8

//Debug LED
#define DEBUG_LED 4

//Constantes
#define KBPS_250 (RH_NRF24::DataRate250kbps)
#define MBPS_1   (RH_NRF24::DataRate1Mbps)
#define MBPS_2   (RH_NRF24::DataRate2Mbps)
#define PW_0DB   (RH_NRF24::TransmitPower0dBm)
#define MAX_MSG_LEN (RH_NRF24_MAX_MESSAGE_LEN)

RH_NRF24 nrf24(CE_PIN, CSN_PIN);

//Variables de estado botones
bool btn_pressed_1 = false;
bool btn_pressed_2 = false;

//Setup
void setup(void) 
{
 //Init Button
  pinMode(BTN_PIN_1, INPUT);
  pinMode(BTN_PIN_2, INPUT);

  //Init DEBUG LED
  pinMode(DEBUG_LED, OUTPUT);

  //ISR for BTN1 IRQ
  attachInterrupt(digitalPinToInterrupt(BTN_PIN_1), btn_event_1, RISING);

  //ISR for BTN2 IRQ
  attachInterrupt(digitalPinToInterrupt(BTN_PIN_2), btn_event_2, RISING);

  //Init NRF24 
  if (!nrf24.init())
    digitalWrite(DEBUG_LED, HIGH);
    
  //Set Channel  
  if (!nrf24.setChannel(2))
    digitalWrite(DEBUG_LED, HIGH);

  //RF Settings
  if (!nrf24.setRF(KBPS_250, PW_0DB))
    digitalWrite(DEBUG_LED, HIGH);
}

//ISR BTN 1
void btn_event_1(void) 
{
  btn_pressed_1 = true;
}

//ISR BTN 2
void btn_event_2(void) 
{
  btn_pressed_2 = true;
}

//Send data via NRF24
void enviarBTN(const char *msg) 
{
  nrf24.setModeTx();
  delay(100); //Wait for wake up

  //Send Message
  uint8_t data[5];
  strncpy((char*)data, msg, sizeof(data));
  nrf24.send(data, sizeof(data));
  nrf24.waitPacketSent();
}

//Loop
void loop(void) 
{
  if (btn_pressed_1 == true) 
  {
    btn_pressed_1 = false;
    enviarBTN("BTN1");
  }

  if (btn_pressed_2 == true) 
  {
    btn_pressed_2 = false;
    enviarBTN("BTN2");
  }

  //Sleep Nano and NRF24 until Watchdog or external interrupt
  nrf24.sleep();
  LowPower.powerDown(SLEEP_60MS, ADC_OFF, BOD_OFF);   //SLEEP_30MS, SLEEP_60MS, SLEEP_120MS
}

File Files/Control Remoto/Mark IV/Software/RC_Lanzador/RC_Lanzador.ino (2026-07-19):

//********************************************************
//              Lanzador con NRF24 (Servidor)
//********************************************************

#include <SPI.h>
#include <RH_NRF24.h>

//Constantes
#define KBPS_250 (RH_NRF24::DataRate250kbps)
#define MBPS_1   (RH_NRF24::DataRate1Mbps)
#define MBPS_2   (RH_NRF24::DataRate2Mbps)
#define PW_0DB   (RH_NRF24::TransmitPower0dBm)
#define MAX_MSG_LEN (RH_NRF24_MAX_MESSAGE_LEN)

RH_NRF24 nrf24;

uint32_t cont = 0;

//Setup
void setup() 
{
  Serial.begin(9600);

  //Init NRF24
  if (!nrf24.init())
    Serial.println("NRF24 Init failed...");
  if (!nrf24.setChannel(2))
    Serial.println("Set Channel failed...");
  if (!nrf24.setRF(KBPS_250, PW_0DB))
    Serial.println("NRF24 Settings failed...");    

    Serial.println("Lanzador inicializado y listo");
}

//Loop
void loop()
{
  if (nrf24.available())
  { 
    uint8_t buf[MAX_MSG_LEN];
    uint8_t len = sizeof(buf);

    //Waits for message
    if (nrf24.recv(buf, &len))
    {
      cont++;
      Serial.print("Recibido Nº");
      Serial.print(cont);
      Serial.print(": ");
      Serial.println((char*)buf);
    }
    else
    {
      Serial.println("Received failed...");
    }
  }
}
